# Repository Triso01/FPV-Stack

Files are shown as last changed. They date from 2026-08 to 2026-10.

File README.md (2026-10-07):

# My FPV Stack

Note:
  I made it because I want to learn how to make BLDC-ESCs, 
  Designing my own FPV Stack, it WILL have errors, so do NOT use it in your Drone!
  The 4 in 1 ESC will be continued later, I don not have the experience to finish it yet.
  
## Flight Controller:

- No Analog OSD, made for BetaFPV P1 or optionally Walksnail and DJI
- BEC: 5V 3A; 9V 3A
- IMU (Gyro): ICM-20602
- STM32F405
- Buzzer Pads
- 1 UART free to use e.g. for GPS

ESC and Flight Controller Connector Pinout:

| [1]  | [2] | [3]  | [4]  | [5] | [6] | [7] | [8] |
|---|-----|---|---|-----|-----|-----|-----|
| VBAT | GND | CUR  | TEL  | M1  | M2  | M3  | M4  |



VTX Connector Pinout:

| [1] | [2] | [3]  | [4] | [5] | [6] |
|-----|-----|---|---|-----|-----|
| 5V  | GND | U1_TX| U1_RX | GND | NC  |







## ESCs:
Based on EFM88B21, FD6288 and PSMN1R4-40YLDX.
  - Bluejay (Layout A), BLHeli_S compatible
  - Dshot bidirectional








## ESC distribution board:
10V Buck, 3,3V LDO and the ampmeter









[Will be finished, when I have more experience]:
4in1 ESC:
Based on EFM8BB21, FD6288Q and 24 PSMN1R4-40YLDX.
The PCB size is not final yet, it WILL change.
  - Bluejay (Laout A), BLHeli_S compatible
  - Dshot bidirectional compatible
  - Current Sensor: INA168 with a 0.5mOhms shunt
  - LMR14010 10V Buck to provide Gate voltage
  - AP2204K LDO 10V -> 3.3V
(You can see "pictures" when opening the PCB Files with KiCad)

## What are the boards for?

The Flight Controller (FC) is the main control board and the "brain" of the FPV stack. It runs the flight-control firmware and uses its IMU to measure the drone's movement, which is required for stable flight.

The ESC Distribution Board distributes one battery connection to four individual ESCs. It also generates the 10 V gate-driver supply, and measures the total battery current.

Each Electronic Speed Controller (ESC) drives one three-phase brushless motor. Designing this small, high-current board was the most challenging part of the project.

## Now the expensive things (duhhh):

PCBs:


Settings for FC:



Settings for ESC:



Settings for ESC-Distrib:



(You can change Surface Finish and Color if you want another Color or a higher quality finish)

Parts:
1. Select the columns like this
2. Click "Create BOM"
Bildschirmfoto 2026-09-21 um 22 52 28

3. Click on "Add to Cart"


## Grouped BOM

| Part group | Qty used | Price (USD) |
|---|---:|---:|
| Resistors, including the current shunt | 68 | $3.09 |
| Capacitors | 85 | $9.99 |
| Inductors | 3 | $2.40 |
| Semiconductors and ICs | 57 | $73.05 |
| USB receptacle | 1 | $1.50 |
| Switches | 2 | $0.53 |
| Cables | 6 | $0.00 |
| PCBs | 6 | $103.30 |
| Shipping | 1-2 | ~$20-40 |
| **Total** | | **$195.79** |

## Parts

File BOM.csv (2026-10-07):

Item Name | Qty | Price (total) (USD) | Notes
10 ohm 1% 0201 gate resistor - SAE 1RC0201F1009 | 24 | $0.12 | Replacement for backordered C105901; same value and package. 50 mW is suitable for 24 kHz PWM.
AP2204K-3.3 LDO - AP2204K-3.3TRG1 | 1 | $1.88
121 kohm 1% 0402 resistor - SAE 1RC0402F1213 | 1 | $0.18 | Replacement for backordered C112303; same value and package.
128 Mbit SPI flash - W25Q128JVSIQ | 1 | $2.52
12.4 kohm 1% 0402 resistor - 0402WGF1242TCE | 1 | $0.14
1 kohm 1% 0402 resistor - Yageo RC0402FR-071KL | 2 | $0.38 | Replacement for backordered C11702; same value and package.
22 uH power inductor - Bourns SRP7050TA-220M | 1 | $1.14 | Replacement for backordered C1330991; higher current rating and same footprint, but 4.8 mm high instead of 2.8 mm.
High-side current monitor - INA168NA/3K | 1 | $1.01
10 nF 50 V X7R 0402 capacitor - CL05B103KB5NNNC | 1 | $0.50
0.5 milliohm 2 W 2512 shunt - LR2512-22R0005F4 | 1 | $0.83
Flight-controller MCU - STM32F405RGT6 | 1 | $6.01
1 uF 50 V X5R 0603 capacitor - Taiyo Yuden UMK107BJ105KA-T | 9 | $0.77 | Replacement for backordered C15849; same capacitance, voltage and package.
100 nF 50 V X7R 0603 capacitor - Yageo CC0603KRX7R9BB104 | 4 | $0.62 | Replacement for backordered C1591; same capacitance, voltage and package.
60 V 2 A Schottky diode - SS26 | 1 | $0.60
100 nF 50 V X7R 0805 capacitor - CL21B104KBCNNNC | 4 | $0.30
NPN transistor - BC817-40 | 1 | $0.11
1 uF 50 V X7R 1206 capacitor - AC1206KKX7R9BB105 | 4 | $0.53
40 V 1 A buck converter - LMR14010ADDCT | 1 | $2.39
2.2 uF 16 V X5R 0603 capacitor - CL10A225KO8NNNC | 1 | $0.91
100 kohm 1% 0402 resistor - 0402WGF1003TCE | 2 | $0.25
10 kohm 1% 0402 resistor - 0402WGF1002TCE | 5 | $0.34
200 kohm 1% 0402 resistor - 0402WGF2003TCE | 1 | $0.18
24.9 kohm 1% 0402 resistor - Yageo RC0402FR-0724K9L | 1 | $0.14 | Replacement for backordered C25874; same value and package.
5.1 kohm 1% 0402 resistor - 0402WGF5101TCE | 2 | $0.24
100 kohm 1% 0201 resistor - 0201WMF1003TEE | 12 | $0.15
22 uF 16 V X5R 0603 capacitor - CL10A226MO7JZNC | 4 | $0.34
USB Type-C 16-pin receptacle - TYPE-C 16PIN 2MD(073) | 1 | $1.50
40 V Schottky diode - BAT54KFILM | 12 | $1.43
22 uF 25 V X5R 1206 capacitor - 1206X226M250NT | 1 | $1.22
1 nF 50 V X7R 0201 capacitor - FN03X102K500PLG | 12 | $0.20
100 nF 16 V X5R 0201 capacitor - TCC0201X5R104K160ZT | 20 | $0.22
Three-phase gate driver - Fortior FD6288Q | 4 | $9.49
10 uF 50 V X7R 1210 capacitor - C3225X7R1H106MT000E | 3 | $1.88
40 V LFPAK56 MOSFET - VBsemi VBGED1401 | 24 | $33.12 | Replacement for backordered C458253; same LFPAK56 footprint and 40 V rating, with lower typical RDS(on). Prototype testing is required.
10 kohm 1% 0201 resistor - 0201WMF1002TEE | 16 | $0.14
2.2 uF 10 V X6S 0402 capacitor - GRT155C81A225KE13D | 3 | $0.49
220 nF 50 V X5R 0402 capacitor - GRM155R61H224KE01D | 2 | $0.97
1 uF 25 V X5R 0402 capacitor - CL05A105KA5NQNC | 4 | $0.54
3.0 V LDO - MCP1700T-3002E/TT | 1 | $0.52
2.2 uH power inductor - ANR3015T2R2M | 1 | $0.83
Reset/boot tactile switch - TS-1088-AR02016 | 2 | $0.53
26 V TVS diode - SMBJ26A | 1 | $0.81
3.3 uH power inductor - ANR3015T3R3M | 1 | $0.43
ESC MCU - EFM8BB21F16G-C-QFN20R | 4 | $5.06
40 V 1 A Schottky diode - 1N5819HW-7-F | 1 | $0.57
36 V 3 A buck converter - LMR33630ADDAR | 2 | $1.51
100 nF 50 V X7R 0402 capacitor - CL05B104KB5NNNC | 13 | $0.50
6-axis IMU - ICM-20602 | 1 | $6.02
3-wire ESC connection cable | 4 | $0.00
8-wire FC-to-distribution cable | 1 | $0.00
6-wire VTX cable | 1 | $0.00
ESC distribution PCB | 1 | $49.80
Individual ESC PCB | 4 | $49.50
Flight-controller PCB | 1 | $4.00
JLCPCB estimated shipping | 1 | $21.93
Total Price (USD) |  | $195.79 | Prices checked at LCSC and JLCPCB on 2026-10-07.

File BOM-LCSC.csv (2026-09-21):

Description | Customer Part Number | Package | Quantity | LCSC Part Number
10Ohm | ESC:R2,R3,R4,R5,R6,R7 (x4) | Resistor_SMD:R_0201_0603Metric | 24 | C105901
AP2204K-3.3 | ESC-Verteiler:U1 | Package_TO_SOT_SMD:SOT-23-5 | 1 | C112032
121kOhm | ESC-Verteiler:R8 | Resistor_SMD:R_0402_1005Metric | 1 | C112303
W25Q128JVS | FC:U6 | Package_SO:SOIC-8_5.3x5.3mm_P1.27mm | 1 | C113767
12.4kOhm | FC:R7 | Resistor_SMD:R_0402_1005Metric_Pad0.72x0.64mm_HandSolder | 1 | C11692
1kOhm | FC:R2,R5 | Resistor_SMD:R_0402_1005Metric_Pad0.72x0.64mm_HandSolder | 2 | C11702
22uH | ESC-Verteiler:L1 | Inductor_SMD:L_Bourns_SRP7028A_7.3x6.6mm | 1 | C1330991
INA168 | ESC-Verteiler:U11 | Package_TO_SOT_SMD:SOT-23-5 | 1 | C134294
10nf | FC:C6 | Capacitor_SMD:C_0402_1005Metric_Pad0.74x0.62mm_HandSolder | 1 | C15195
0.5mOhms | ESC-Verteiler:R31 | Resistor_SMD:R_2512_6332Metric | 1 | C154666
STM32F405RGTx | FC:U1 | Package_QFP:LQFP-64_10x10mm_P0.5mm | 1 | C15742
1uf | ESC:C26,C43 (x4); ESC-Verteiler:C1 | Capacitor_SMD:C_0603_1608Metric | 9 | C15849
100nf | ESC:C27 (x4) | Capacitor_SMD:C_0603_1608Metric | 4 | C1591
D | ESC-Verteiler:D1 | Diode_SMD:D_SMA | 1 | C169419
100nf | ESC-Verteiler:C7,C9,C10,C12 | Capacitor_SMD:C_0805_2012Metric | 4 | C1711
BC817 | FC:Q1 | Package_TO_SOT_SMD:SOT-23 | 1 | C181151
1uf | ESC-Verteiler:C6,C8,C11,C13 | Capacitor_SMD:C_1206_3216Metric | 4 | C1853626
LMR14010ADDCT | ESC-Verteiler:U3 | Package_TO_SOT_SMD:TSOT-23-6 | 1 | C2070867
2.2uf | ESC-Verteiler:C2 | Capacitor_SMD:C_0603_1608Metric | 1 | C23630
100kOhm | FC:R3,R6 | Resistor_SMD:R_0402_1005Metric_Pad0.72x0.64mm_HandSolder | 2 | C25741
10kOhm | FC:R1,R8,R9,R10; ESC-Verteiler:R9 | Resistor_SMD:R_0402_1005Metric | 5 | C25744
200kOhm | ESC-Verteiler:R34 | Resistor_SMD:R_0402_1005Metric | 1 | C25764
24.9kOhm | FC:R4 | Resistor_SMD:R_0402_1005Metric_Pad0.72x0.64mm_HandSolder | 1 | C25874
5.1kOhm | FC:R11,R12 | Resistor_SMD:R_0402_1005Metric_Pad0.72x0.64mm_HandSolder | 2 | C25905
100kOhm | ESC:R32,R33,R35 (x4) | Resistor_SMD:R_0201_0603Metric | 12 | C270364
22uf | FC:C17,C18,C21,C22 | Capacitor_SMD:C_0603_1608Metric_Pad1.08x0.95mm_HandSolder | 4 | C2762594
TYPE-C 16PIN 2MD | FC:USB1 | EasyEDA:USB-C-SMD_TYPE-C-16PIN-2MD-073 | 1 | C2765186
BAT54 | ESC:D2,D3,D4 (x4) | Diode_SMD:D_SOD-523 | 12 | C283259
22uf | ESC-Verteiler:C4 | Capacitor_SMD:C_1206_3216Metric | 1 | C2858005
1nf | ESC:C22,C23,C24 (x4) | Capacitor_SMD:C_0201_0603Metric | 12 | C2874741
100nf | ESC:C1,C5,C6,C7,C44 (x4) | Capacitor_SMD:C_0201_0603Metric | 20 | C2903663
FD6288Q | ESC:U2 (x4) | Package_DFN_QFN:HVQFN-24-1EP_4x4mm_P0.5mm_EP2.6x2.6mm | 4 | C328453
10uf | FC:C8,C12; ESC-Verteiler:C5 | Capacitor_SMD:C_1210_3225Metric | 3 | C342670
PSMN1R4-40YLDX | ESC:Q1,Q2,Q3,Q6,Q7,Q8 (x4) | Package_TO_SOT_SMD:LFPAK56 | 24 | C458253
10kOhm | ESC:R1,R36,R37,R38 (x4) | Resistor_SMD:R_0201_0603Metric | 16 | C473048
2.2uF | FC:C5,C27,C28 | Capacitor_SMD:C_0402_1005Metric_Pad0.74x0.62mm_HandSolder | 3 | C5119302
220nf | FC:C7,C11 | Capacitor_SMD:C_0402_1005Metric_Pad0.74x0.62mm_HandSolder | 2 | C5159775
1uf | FC:C1,C2,C9,C13 | Capacitor_SMD:C_0402_1005Metric_Pad0.74x0.62mm_HandSolder | 4 | C52923
MCP1700x-300xxTT | FC:U2 | Package_TO_SOT_SMD:SOT-23 | 1 | C62244
2.2uH | FC:L1 | Inductor_SMD:L_APV_ANR3015 | 1 | C6364793
Taster (RST/BOOT) | FC:SW1,SW2 | EasyEDA:SW-SMD_L3.9-W3.0-P4.45 | 2 | C720477
D | ESC-Verteiler:D14 | Diode_SMD:D_SMB | 1 | C726831
3.3uH | FC:L2 | Inductor_SMD:L_APV_ANR3015 | 1 | C7427087
EFM8BB21F16G-C-QFN20R | ESC:U1 (x4) | Package_DFN_QFN:SiliconLabs_QFN-20-1EP_3x3mm_P0.5mm_EP1.8x1.8mm | 4 | C80713
D | FC:D1 | Diode_SMD:D_SOD-123 | 1 | C82544
LMR33630ADDA | FC:U4,U5 | Package_SO:Texas_HSOP-8-1EP_3.9x4.9mm_P1.27mm_ThermalVias | 2 | C841384
100nf | FC:C3,C4,C10,C14,C15,C16,C19,C20,C23,C24,C25,C26; ESC-Verteiler:C3 | Capacitor_SMD:C_0402_1005Metric | 13 | C960916
ICM-20602 | FC:U3 | Package_LGA:LGA-16_3x3mm_P0.5mm_LayoutBorder3x5y | 1 | C97633

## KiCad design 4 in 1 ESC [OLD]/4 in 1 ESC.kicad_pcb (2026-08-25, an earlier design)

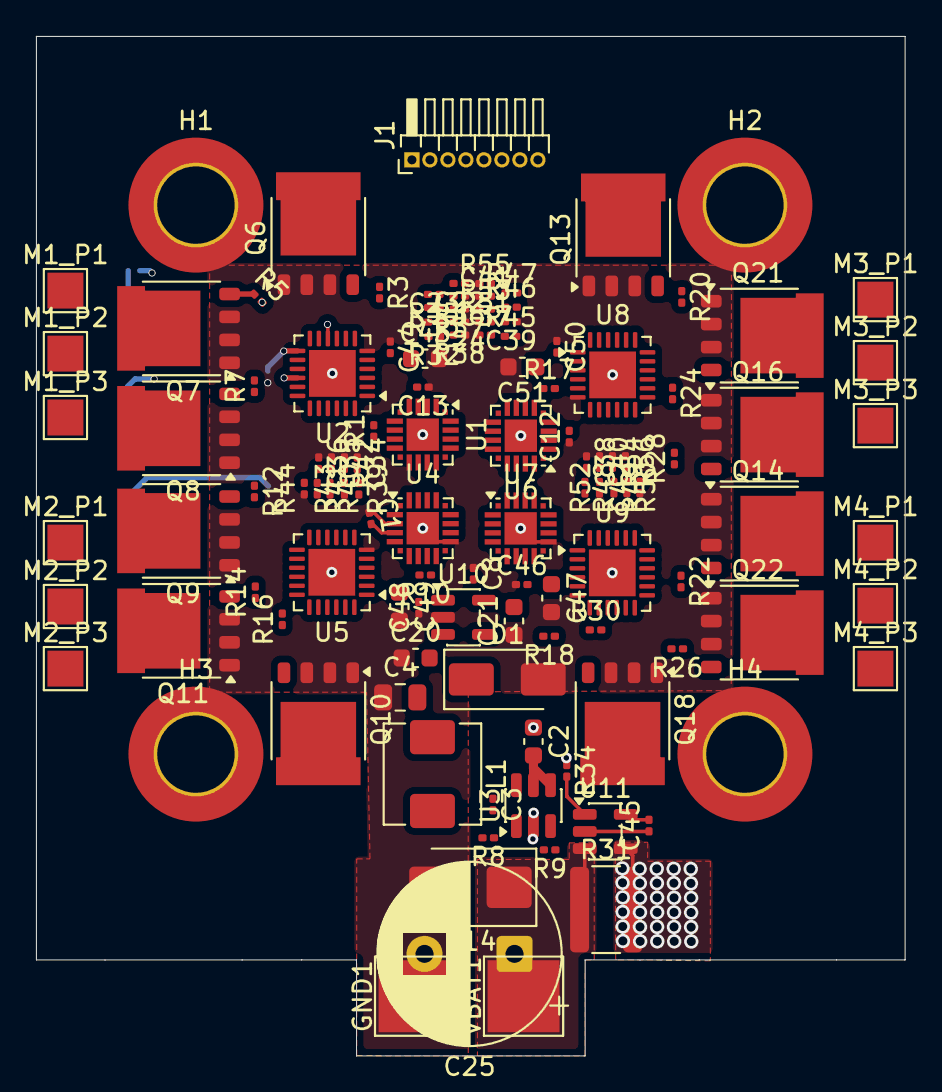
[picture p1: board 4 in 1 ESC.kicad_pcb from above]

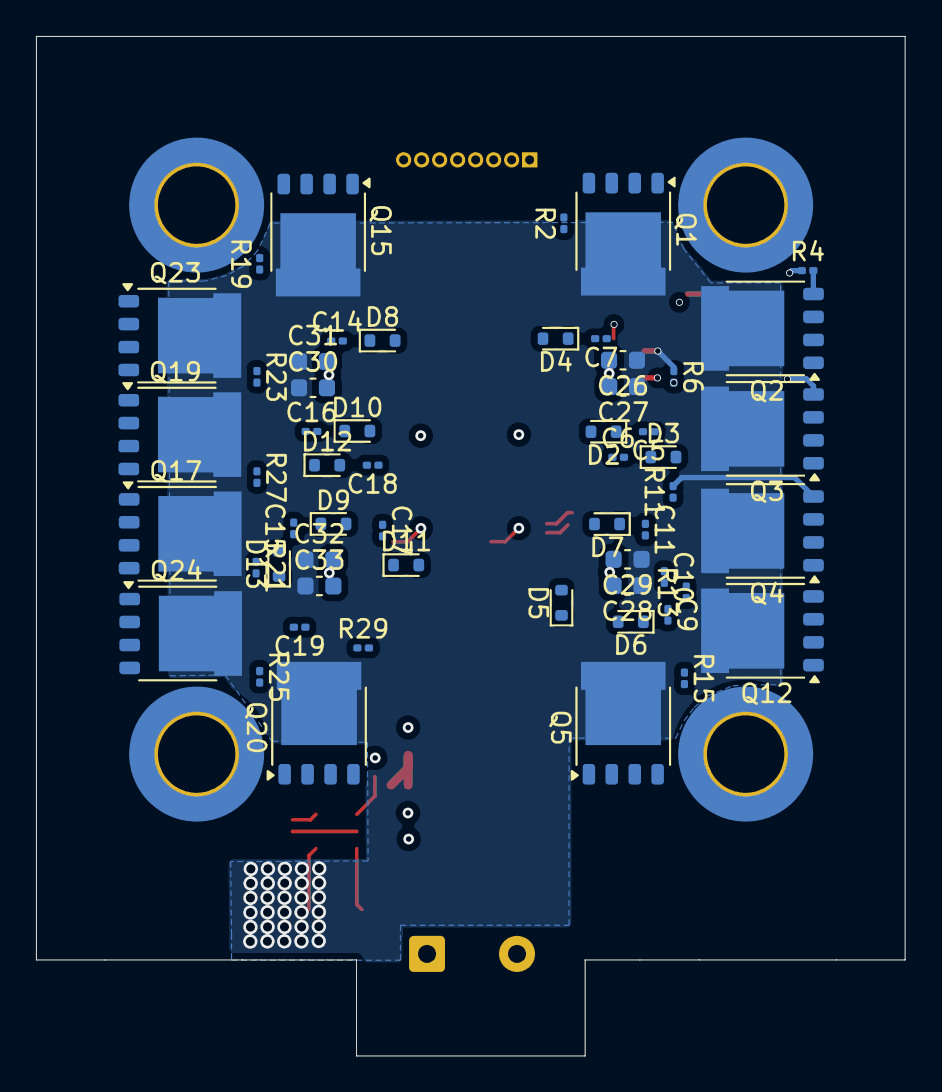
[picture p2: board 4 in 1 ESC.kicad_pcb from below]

Board: 4 copper layers, 48.3 x 56.6 mm, 176 parts (56 on the bottom side), 125 nets.

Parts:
C1, C3, C5, C6, C7, C8, C9, C10, C11, C12, C13, C14, C15, C16, C17, C18, C19, C44, C45, C46, C48, C50: 100nf; C_0201_0603Metric
C2: 10uf; C_0603_1608Metric
C4: 22uf; C_0805_2012Metric
C20, C26, C28, C30, C32, C43, C47, C49, C51: 1uf; C_0603_1608Metric
C21: 2.2uf; C_0603_1608Metric
C22, C23, C24, C34, C35, C36, C37, C38, C39, C40, C41, C42: 1nf; C_0201_0603Metric
C25: 470uf; CP_Radial_D10.0mm_P5.00mm
C27, C29, C31, C33: 100nf; C_0603_1608Metric
D1: D; D_SMA
D2, D3, D4, D5, D6, D7, D8, D9, D10, D11, D12, D13: BAT54; D_SOD-523
D14: D; D_SMB
GND1: TestPoint_Pad_4.0x4.0mm
H1, H2, H3, H4: MountingHole_Pad; MountingHole_4.3mm_M4_DIN965_Pad_TopBottom
J1: Conn_01x08_Socket; PinHeader_1x08_P1.00mm_Horizontal
L1: 22uH; L_Sunlord_MWSA0503S
M1_P1, M1_P2, M1_P3, M2_P1, M2_P2, M2_P3, M3_P1, M3_P2, M3_P3, M4_P1, M4_P2, M4_P3: TestPoint; TestPoint_Pad_2.0x2.0mm
Q1, Q2, Q3, Q4, Q5, Q6, Q7, Q8, Q9, Q10, Q11, Q12, Q13, Q14, Q15, Q16, Q17, Q18, Q19, Q20, Q21, Q22, Q23, Q24: PSMN1R4-40YLDX; LFPAK56
R1, R9, R10, R17, R18, R36, R37, R38, R42, R43, R44, R51, R52, R53, R54, R55, R56: 10kOhm; R_0201_0603Metric
R2, R3, R4, R5, R6, R7, R11, R12, R13, R14, R15, R16, R19, R20, R21, R22, R23, R24, R25, R26, R27, R28, R29, R30: 10Ohm; R_0201_0603Metric
R8: 121kOhm; R_0201_0603Metric
R31: 0.5mOhms; R_1218_3246Metric
R32, R33, R35, R39, R40, R41, R45, R46, R47, R48, R49, R50: 100kOhm; R_0201_0603Metric
R34: 200kOhm; R_0201_0603Metric
U1, U4, U6, U7: EFM8BB21F16G-C-QFN20R; SiliconLabs_QFN-20-1EP_3x3mm_P0.5mm_EP1.8x1.8mm
U2, U5, U8, U9: FD6288Q; HVQFN-24-1EP_4x4mm_P0.5mm_EP2.6x2.6mm
U3: LMR14010ADDCT; TSOT-23-6
U10: AP2204K-3.3; SOT-23-5
U11: INA168; SOT-23-5
VBAT1: TestPoint_Pad_4.0x4.0mm

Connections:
/10V: C4.2, C20.2, C43.1, C44.2, C46.2, C47.1, C48.2, C49.1, C50.2, C51.1, D2.2 (A), D3.2 (A), D4.2 (A), D5.2 (A), D6.2 (A), D7.2 (A), D8.2 (A), D9.2 (A), D10.2 (A), D11.2 (A), D12.2 (A), D13.2 (A), L1.1, R8.2, U2.4 (VCC), U5.4 (VCC), U8.4 (VCC), U9.4 (VCC), U10.1 (VIN), U10.3 (EN)
/CUR: J1.3, R34.2, U11.1
/DSHOT_M1: J1.5, U1.17 (P0.5)
/DSHOT_M2: J1.6, U4.17 (P0.5)
/DSHOT_M3: J1.7, U6.17 (P0.5)
/DSHOT_M4: J1.8, U7.17 (P0.5)
/GND: C1.1, C2.1, C4.1, C8.1, C12.1, C13.1, C20.1, C21.1, C22.1, C23.1, C24.1, C25.2, C26.2, C27.2, C28.2, C29.2, C30.2, C31.2, C32.2, C33.2, C34.1, C35.1, C36.1, C37.1, C38.1, C39.1, C40.1, C41.1, C42.1, C43.2, C44.1, C45.1, C46.1, C47.2, C48.1, C49.2, C50.1, C51.2, D1.2 (A), D14.2 (A), GND1.1 (1_1), H1.1 (1_1), H2.1 (1_1), H3.1 (1_1), H4.1 (1_1), J1.2, Q6.1 (S_1), Q6.2 (S_2), Q6.3 (S_3), Q7.1 (S_1), Q7.2 (S_2), Q7.3 (S_3), Q8.1 (S_1), Q8.2 (S_2), Q8.3 (S_3), Q9.1 (S_1), Q9.2 (S_2), Q9.3 (S_3), Q10.1 (S_1), Q10.2 (S_2), Q10.3 (S_3), Q11.1 (S_1), Q11.2 (S_2), Q11.3 (S_3), Q13.1 (S_1), Q13.2 (S_2), Q13.3 (S_3), Q14.1 (S_1), Q14.2 (S_2), Q14.3 (S_3), Q16.1 (S_1), Q16.2 (S_2), Q16.3 (S_3), Q18.1 (S_1), Q18.2 (S_2), Q18.3 (S_3), Q21.1 (S_1), Q21.2 (S_2), Q21.3 (S_3), Q22.1 (S_1), Q22.2 (S_2), Q22.3 (S_3), R9.2, R34.1, R36.1, R37.1, R38.1, R42.1, R43.1, R44.1, R51.1, R52.1, R53.1, R54.1, R55.1, R56.1, U1.3 (GND), U1.12 (GND), U1.21 (GND), U2.6 (COM), U2.25 (EXP), U3.2 (GND), U4.3 (GND), U4.12 (GND), U4.21 (GND), U5.6 (COM), U5.25 (EXP), U6.3 (GND), U6.12 (GND), U6.21 (GND), U7.3 (GND), U7.12 (GND), U7.21 (GND), U8.6 (COM), U8.25 (EXP), U9.6 (COM), U9.25 (EXP), U10.2 (GND), U11.2 (GND)
/VBAT: C2.2, C26.1, C27.1, C28.1, C29.1, C30.1, C31.1, C32.1, C33.1, J1.1, Q1.5 (D_1), Q2.5 (D_1), Q3.5 (D_1), Q4.5 (D_1), Q5.5 (D_1), Q12.5 (D_1), Q15.5 (D_1), Q17.5 (D_1), Q19.5 (D_1), Q20.5 (D_1), Q23.5 (D_1), Q24.5 (D_1), R31.2, U3.4 (SHDN), U3.5 (VIN), U11.4 (-)
/VDD: C1.2, C8.2, C12.2, C13.2, C21.2, C45.2, R1.1, R10.1, R17.1, R18.1, U1.4 (VDD), U4.4 (VDD), U6.4 (VDD), U7.4 (VDD), U10.5 (VOUT), U11.5 (V+)
/VS1_M1: C5.1, M1_P1.1 (1_1), Q1.1 (S_1), Q1.2 (S_2), Q1.3 (S_3), Q6.5 (D_1), R32.2, U2.18 (VS1)
/VS1_M2: C9.1, M2_P1.1 (1_1), Q4.1 (S_1), Q4.2 (S_2), Q4.3 (S_3), Q9.5 (D_1), R41.2, U5.18 (VS1)
/VS1_M3: C14.1, M3_P1.1 (1_1), Q13.5 (D_1), Q15.1 (S_1), Q15.2 (S_2), Q15.3 (S_3), R47.2, U8.18 (VS1)
/VS1_M4: C15.1, M4_P1.1 (1_1), Q14.5 (D_1), Q17.1 (S_1), Q17.2 (S_2), Q17.3 (S_3), R50.2, U9.18 (VS1)
/VS2_M1: C6.1, M1_P2.1 (1_1), Q2.1 (S_1), Q2.2 (S_2), Q2.3 (S_3), Q7.5 (D_1), R33.2, U2.15 (VS2)
/VS2_M2: C10.1, M2_P2.1 (1_1), Q11.5 (D_1), Q12.1 (S_1), Q12.2 (S_2), Q12.3 (S_3), R40.2, U5.15 (VS2)
/VS2_M3: C16.1, M3_P2.1 (1_1), Q21.5 (D_1), Q23.1 (S_1), Q23.2 (S_2), Q23.3 (S_3), R46.2, U8.15 (VS2)
/VS2_M4: C17.1, M4_P2.1 (1_1), Q22.5 (D_1), Q24.1 (S_1), Q24.2 (S_2), Q24.3 (S_3), R49.2, U9.15 (VS2)
/VS3_M1: C7.1, M1_P3.1 (1_1), Q3.1 (S_1), Q3.2 (S_2), Q3.3 (S_3), Q8.5 (D_1), R35.2, U2.12 (VS3)
/VS3_M2: C11.1, M2_P3.1 (1_1), Q5.1 (S_1), Q5.2 (S_2), Q5.3 (S_3), Q10.5 (D_1), R39.2, U5.12 (VS3)
/VS3_M3: C18.1, M3_P3.1 (1_1), Q16.5 (D_1), Q19.1 (S_1), Q19.2 (S_2), Q19.3 (S_3), R45.2, U8.12 (VS3)
/VS3_M4: C19.1, M4_P3.1 (1_1), Q18.5 (D_1), Q20.1 (S_1), Q20.2 (S_2), Q20.3 (S_3), R48.2, U9.12 (VS3)
unnamed: C3.1, D1.1 (K), L1.2, U3.6 (SW)
unnamed: C5.2, D2.1 (K), U2.20 (VB1)
unnamed: C6.2, D3.1 (K), U2.17 (VB2)
unnamed: C7.2, D4.1 (K), U2.14 (VB3)
unnamed: C9.2, D5.1 (K), U5.20 (VB1)
unnamed: C10.2, D6.1 (K), U5.17 (VB2)
unnamed: C11.2, D7.1 (K), U5.14 (VB3)
unnamed: C14.2, D8.1 (K), U8.20 (VB1)
unnamed: C15.2, D9.1 (K), U9.20 (VB1)
unnamed: C16.2, D10.1 (K), U8.17 (VB2)
unnamed: C17.2, D11.1 (K), U9.17 (VB2)
unnamed: C18.2, D12.1 (K), U8.14 (VB3)
unnamed: C19.2, D13.1 (K), U9.14 (VB3)
unnamed: C25.1, D14.1 (K), R31.1, U11.3 (+), VBAT1.1 (1_1)
unnamed: Q1.4 (G), R2.2
unnamed: Q2.4 (G), R4.2
unnamed: Q3.4 (G), R6.2
unnamed: Q4.4 (G), R11.2
unnamed: Q5.4 (G), R15.2
unnamed: Q6.4 (G), R3.1
unnamed: Q7.4 (G), R5.1
unnamed: Q8.4 (G), R7.1
unnamed: Q9.4 (G), R12.1
unnamed: Q10.4 (G), R16.1
unnamed: Q11.4 (G), R14.1
unnamed: Q12.4 (G), R13.2
unnamed: Q13.4 (G), R20.1
unnamed: Q14.4 (G), R22.1
unnamed: Q15.4 (G), R19.2
unnamed: Q16.4 (G), R28.1
unnamed: Q17.4 (G), R21.2
unnamed: Q18.4 (G), R30.1
unnamed: Q19.4 (G), R27.2
unnamed: Q20.4 (G), R29.2
unnamed: Q21.4 (G), R24.1
unnamed: Q22.4 (G), R26.1
unnamed: Q23.4 (G), R23.2
unnamed: Q24.4 (G), R25.2
unnamed: C24.2, R32.1, R38.2, U1.1 (P0.1)
unnamed: C23.2, R33.1, R37.2, U1.20 (P0.2)
unnamed: C22.2, R35.1, R36.2, U1.19 (P0.3)
unnamed: U1.14 (P1.0), U2.22 (HIN1)
unnamed: U1.13 (P1.1), U2.1 (LIN1)
unnamed: U1.11 (P1.2), U2.23 (HIN2)
unnamed: U1.10 (P1.3), U2.2 (LIN2)
unnamed: U1.9 (P1.4), U2.24 (HIN3)
unnamed: U1.8 (P1.5), U2.3 (LIN3)
unnamed: R1.2, U1.5 (RSTb/C2CK)
unnamed: R2.1, U2.19 (HO1)
unnamed: R4.1, U2.16 (HO2)
unnamed: R6.1, U2.13 (HO3)
unnamed: R3.2, U2.11 (LO1)
unnamed: R5.2, U2.10 (LO2)
unnamed: R7.2, U2.9 (LO3)
unnamed: C3.2, U3.1 (CB)
unnamed: R8.1, R9.1, U3.3 (FB)
unnamed: C36.2, R41.1, R44.2, U4.1 (P0.1)
unnamed: C35.2, R40.1, R43.2, U4.20 (P0.2)
unnamed: C34.2, R39.1, R42.2, U4.19 (P0.3)
unnamed: U4.14 (P1.0), U5.22 (HIN1)
unnamed: U4.13 (P1.1), U5.1 (LIN1)
unnamed: U4.11 (P1.2), U5.23 (HIN2)
unnamed: U4.10 (P1.3), U5.2 (LIN2)
unnamed: U4.9 (P1.4), U5.24 (HIN3)
unnamed: U4.8 (P1.5), U5.3 (LIN3)
unnamed: R10.2, U4.5 (RSTb/C2CK)
unnamed: R11.1, U5.19 (HO1)
unnamed: R13.1, U5.16 (HO2)
unnamed: R15.1, U5.13 (HO3)
unnamed: R12.2, U5.11 (LO1)
unnamed: R14.2, U5.10 (LO2)
unnamed: R16.2, U5.9 (LO3)
unnamed: C41.2, R47.1, R55.2, U6.1 (P0.1)
unnamed: C39.2, R46.1, R53.2, U6.20 (P0.2)
unnamed: C37.2, R45.1, R51.2, U6.19 (P0.3)
unnamed: U6.14 (P1.0), U8.22 (HIN1)
unnamed: U6.13 (P1.1), U8.1 (LIN1)
unnamed: U6.11 (P1.2), U8.23 (HIN2)
unnamed: U6.10 (P1.3), U8.2 (LIN2)
unnamed: U6.9 (P1.4), U8.24 (HIN3)
unnamed: U6.8 (P1.5), U8.3 (LIN3)
unnamed: R17.2, U6.5 (RSTb/C2CK)
unnamed: C42.2, R50.1, R56.2, U7.1 (P0.1)
unnamed: C40.2, R49.1, R54.2, U7.20 (P0.2)
unnamed: C38.2, R48.1, R52.2, U7.19 (P0.3)
unnamed: U7.14 (P1.0), U9.22 (HIN1)
unnamed: U7.13 (P1.1), U9.1 (LIN1)
unnamed: U7.11 (P1.2), U9.23 (HIN2)
unnamed: U7.10 (P1.3), U9.2 (LIN2)
unnamed: U7.9 (P1.4), U9.24 (HIN3)
unnamed: U7.8 (P1.5), U9.3 (LIN3)
unnamed: R18.2, U7.5 (RSTb/C2CK)
unnamed: R19.1, U8.19 (HO1)
unnamed: R23.1, U8.16 (HO2)
unnamed: R27.1, U8.13 (HO3)
unnamed: R20.2, U8.11 (LO1)
unnamed: R24.2, U8.10 (LO2)
unnamed: R28.2, U8.9 (LO3)
unnamed: R21.1, U9.19 (HO1)
unnamed: R25.1, U9.16 (HO2)
unnamed: R29.1, U9.13 (HO3)
unnamed: R22.2, U9.11 (LO1)
unnamed: R26.2, U9.10 (LO2)
unnamed: R30.2, U9.9 (LO3)

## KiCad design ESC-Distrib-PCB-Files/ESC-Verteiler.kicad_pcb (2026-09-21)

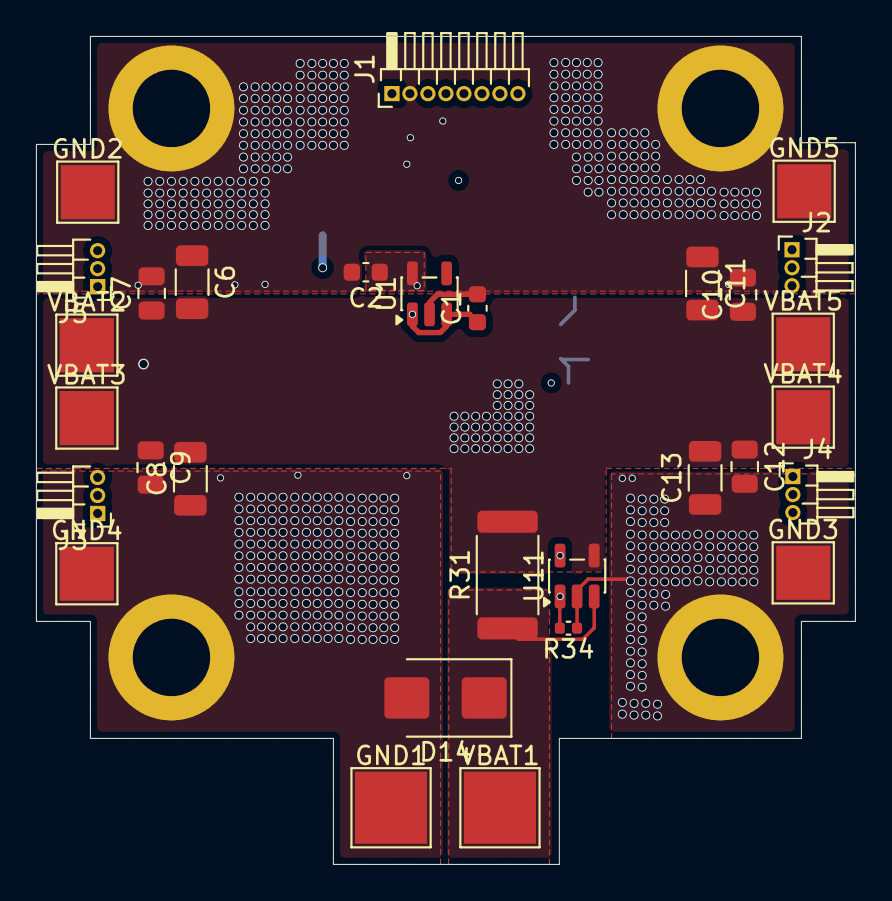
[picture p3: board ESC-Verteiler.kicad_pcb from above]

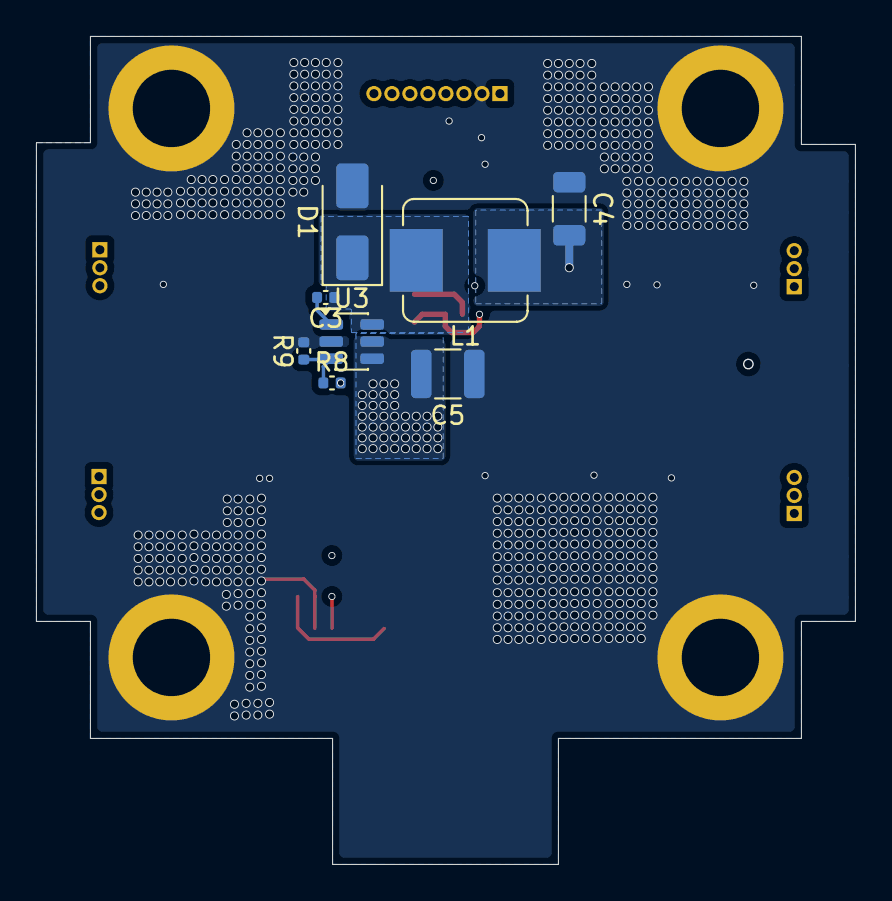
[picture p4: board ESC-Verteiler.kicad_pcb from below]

Board: 4 copper layers, 45.5 x 46.0 mm, 38 parts (8 on the bottom side), 13 nets.

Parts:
C1: 1uf; C_0603_1608Metric
C2: 2.2uf; C_0603_1608Metric
C3: 100nf; C_0402_1005Metric
C4: 22uf; C_1206_3216Metric
C5: 10uf; C_1210_3225Metric
C6, C8, C11, C13: 1uf; C_1206_3216Metric
C7, C9, C10, C12: 100nf; C_0805_2012Metric
D1: D; D_SMA
D14: D; D_SMB
GND1: TestPoint_Pad_4.0x4.0mm
GND2, GND3, GND4, GND5: TestPoint_Pad_3.0x3.0mm
J1: Conn_01x08_Socket; PinHeader_1x08_P1.00mm_Horizontal
J2, J3, J4, J5: Conn_01x03_Pin; PinHeader_1x03_P1.00mm_Horizontal
L1: 22uH; L_Bourns_SRP7028A_7.3x6.6mm
R8: 121kOhm; C_0402_1005Metric
R9: 10kOhm; C_0402_1005Metric
R31: 0.5mOhms; R_2512_6332Metric
R34: 200kOhm; C_0402_1005Metric
U1: AP2204K-3.3; SOT-23-5
U3: LMR14010ADDCT; SOT-23-6
U11: INA168; SOT-23-5
VBAT1: TestPoint_Pad_4.0x4.0mm
VBAT2, VBAT3, VBAT4, VBAT5: TestPoint_Pad_3.0x3.0mm

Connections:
/10V: C1.1, C4.2, J2.1, J3.3, J4.1, J5.3, L1.1, R8.2, U1.1 (VIN), U1.3 (EN)
/CUR: J1.3, R34.2, U11.1
/DSHOT_M1: J1.8, J3.2
/DSHOT_M2: J1.7, J5.2
/DSHOT_M3: J1.6, J2.2
/DSHOT_M4: J1.5, J4.2
/GND: C1.2, C2.2, C4.1, C5.1, C6.1, C7.2, C8.1, C9.2, C10.2, C11.1, C12.2, C13.1, D1.2 (A), D14.2 (A), GND1.1 (1_1), GND2.1 (1_1), GND3.1 (1_1), GND4.1 (1_1), GND5.1 (1_1), J1.2, R9.2, R34.1, U1.2 (GND), U3.2 (GND), U11.2 (GND)
/VBAT: C5.2, C6.2, C7.1, C8.2, C9.1, C10.1, C11.2, C12.1, C13.2, J1.1, R31.2, U3.4 (SHDN), U3.5 (VIN), U11.4 (-), VBAT2.1 (1_1), VBAT3.1 (1_1), VBAT4.1 (1_1), VBAT5.1 (1_1)
/VDD: C2.1, J2.3, J3.1, J4.3, J5.1, U1.5 (VOUT), U11.5 (V+)
unnamed: C3.1, D1.1 (K), L1.2, U3.6 (SW)
unnamed: D14.1 (K), R31.1, U11.3 (+), VBAT1.1 (1_1)
unnamed: C3.2, U3.1 (CB)
unnamed: R8.1, R9.1, U3.3 (FB)

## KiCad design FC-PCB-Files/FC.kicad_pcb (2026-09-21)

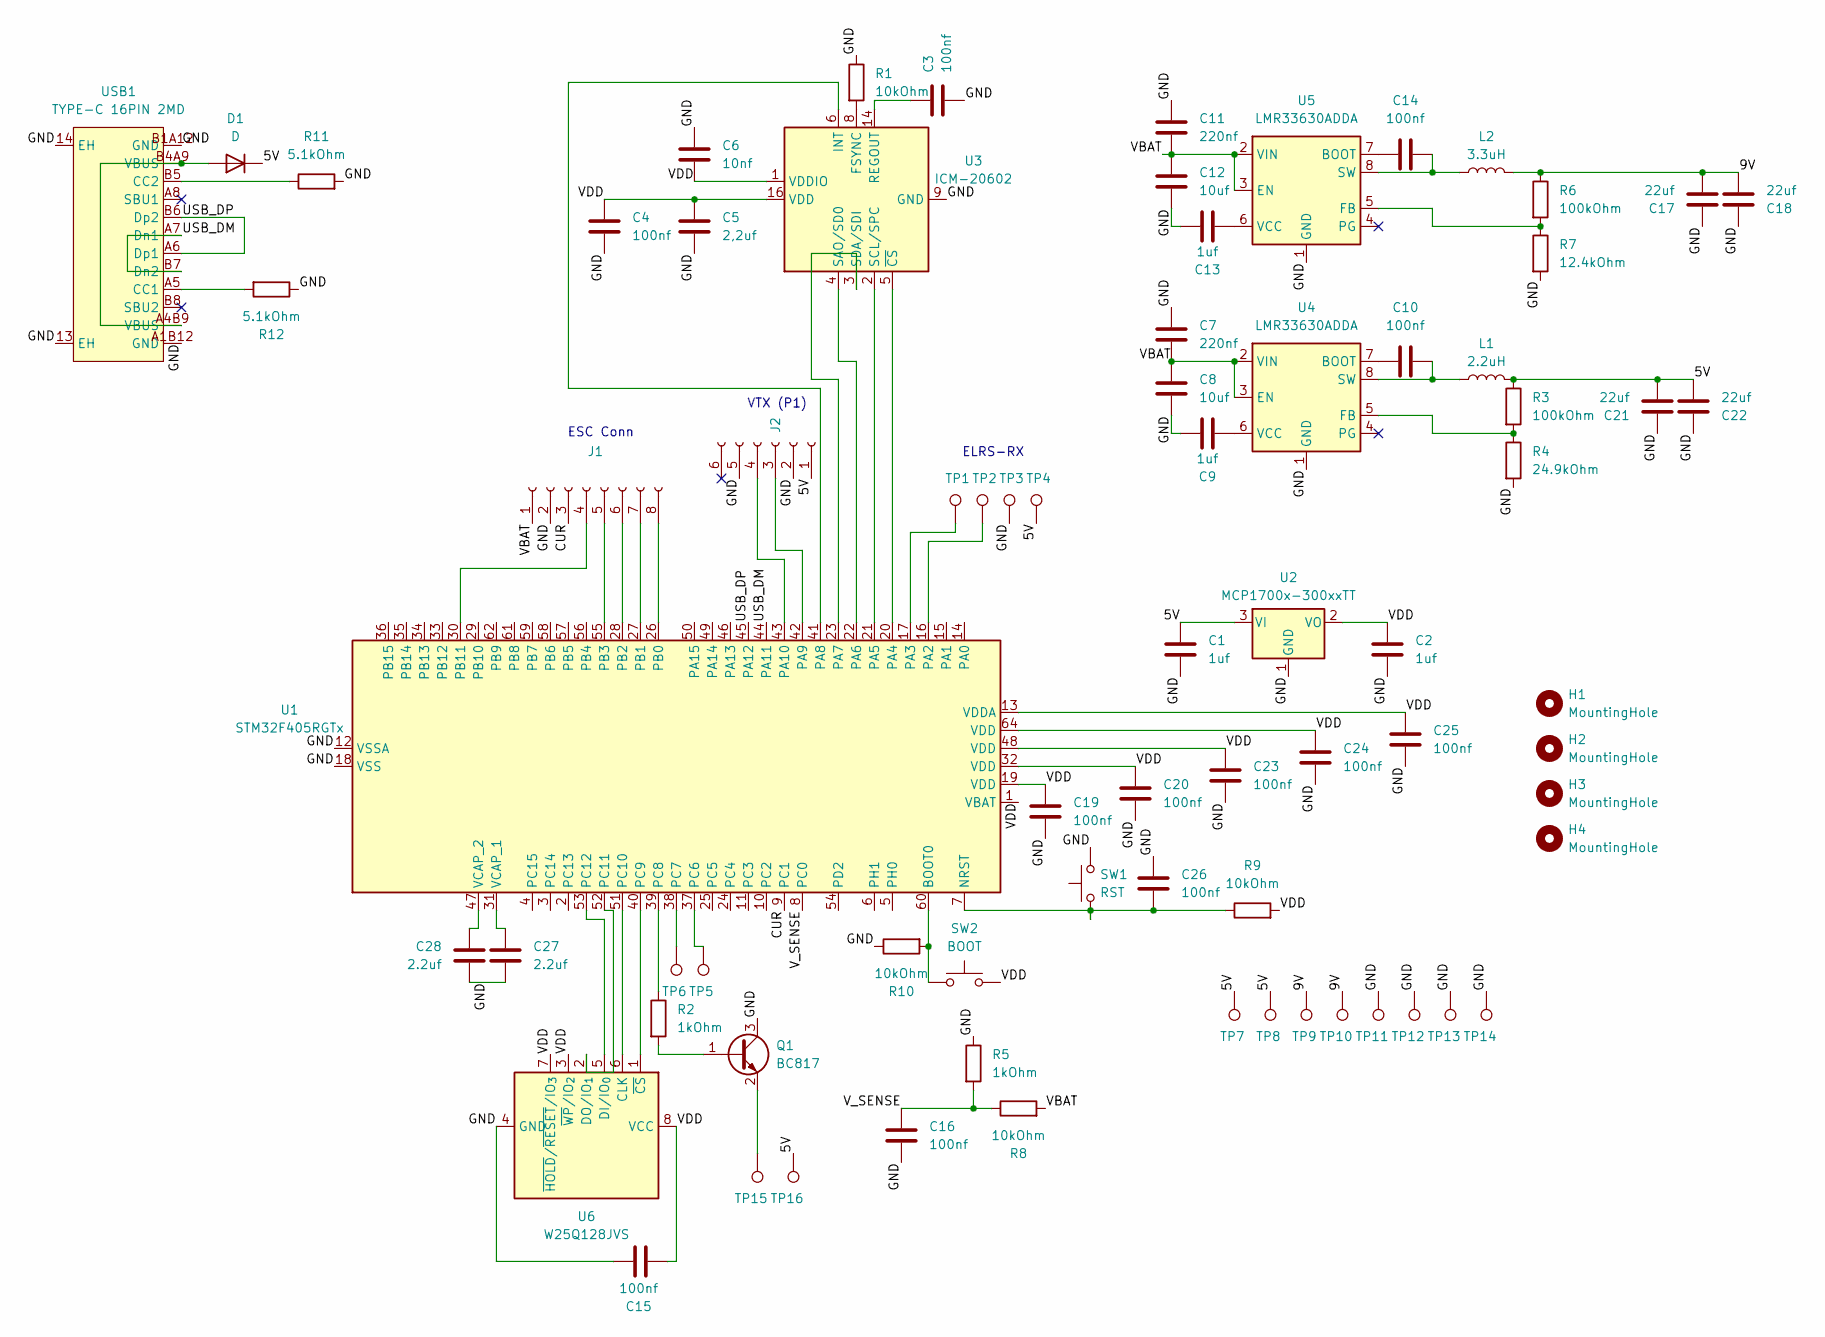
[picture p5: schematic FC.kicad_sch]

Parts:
C1, C2, C9, C13: 1uf; C_0402_1005Metric_Pad0.74x0.62mm_HandSolder
C3, C4, C10, C14, C15, C16, C19, C20, C23, C24, C25, C26: 100nf; C_0402_1005Metric_Pad0.74x0.62mm_HandSolder
C5: 2,2uf; C_0402_1005Metric_Pad0.74x0.62mm_HandSolder
C6: 10nf; C_0402_1005Metric_Pad0.74x0.62mm_HandSolder
C7, C11: 220nf; C_0402_1005Metric_Pad0.74x0.62mm_HandSolder
C8, C12: 10uf; C_0805_2012Metric
C17, C18, C21, C22: 22uf; C_0603_1608Metric_Pad1.08x0.95mm_HandSolder
C27, C28: 2.2uf; C_0402_1005Metric_Pad0.74x0.62mm_HandSolder
D1: D; D_SOD-123
H1, H2, H3, H4: MountingHole; MountingHole_4.3mm_M4_DIN965_Pad_TopOnly
J1: Conn_01x08_Socket; PinHeader_1x08_P1.00mm_Horizontal
J2: Conn_01x06_Socket; PinHeader_1x06_P1.00mm_Horizontal
L1: 2.2uH; L_APV_ANR3015
L2: 3.3uH; L_APV_ANR3015
Q1: BC817; SOT-23
R1, R8, R9, R10: 10kOhm; R_0402_1005Metric_Pad0.72x0.64mm_HandSolder
R2, R5: 1kOhm; R_0402_1005Metric_Pad0.72x0.64mm_HandSolder
R3, R6: 100kOhm; R_0402_1005Metric_Pad0.72x0.64mm_HandSolder
R4: 24.9kOhm; R_0402_1005Metric_Pad0.72x0.64mm_HandSolder
R7: 12.4kOhm; R_0402_1005Metric_Pad0.72x0.64mm_HandSolder
R11, R12: 5.1kOhm; R_0402_1005Metric_Pad0.72x0.64mm_HandSolder
SW1: RST; SW-SMD_L3.9-W3.0-P4.45
SW2: BOOT; SW-SMD_L3.9-W3.0-P4.45
TP1, TP2, TP3, TP4, TP5, TP6, TP7, TP8, TP9, TP10, TP11, TP12, TP13, TP14, TP15, TP16: TestPoint; TestPoint_Pad_D1.5mm
U1: STM32F405RGTx; LQFP-64_10x10mm_P0.5mm
U2: MCP1700x-300xxTT; SOT-23
U3: ICM-20602; LGA-16_3x3mm_P0.5mm_LayoutBorder3x5y
U4, U5: LMR33630ADDA; Texas_HSOP-8-1EP_3.9x4.9mm_P1.27mm_ThermalVias
U6: W25Q128JVS; SOIC-8_5.3x5.3mm_P1.27mm
USB1: TYPE-C 16PIN 2MD; USB-C-SMD_TYPE-C-16PIN-2MD-073; MPN TYPE-C 16PIN 2MD(073); LCSC Part C2765186

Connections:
/5V: C1.1, C21.2, C22.2, D1.1 (K), J2.1, L1.2, R3.1, TP4.1 (1_1), TP7.1 (1_1), TP8.1 (1_1), TP16.1 (1_1), U2.3 (VI)
/9V: C17.2, C18.2, L2.2, R6.1, TP9.1 (1_1), TP10.1 (1_1)
/CUR: J1.3, U1.9 (PC1)
/GND: C1.2, C2.2, C3.2, C4.2, C5.2, C6.1, C7.1, C8.2, C9.2, C11.1, C12.2, C13.2, C15.2, C16.2, C17.1, C18.1, C19.2, C20.2, C21.1, C22.1, C23.2, C24.2, C25.2, C26.1, C27.2, C28.2, J1.2, J2.2, J2.5, Q1.3 (C), R1.1, R4.2, R5.1, R7.2, R10.1, R11.2, R12.1, SW1.2, TP3.1 (1_1), TP11.1 (1_1), TP12.1 (1_1), TP13.1 (1_1), TP14.1 (1_1), U1.12 (VSSA), U1.18 (VSS), U1.63 (VSS), U2.1 (GND), U3.9 (GND), U3.10 (GND), U3.11 (GND), U3.12 (GND), U3.13 (GND), U3.15 (GND), U4.1 (GND), U4.9 (GND), U5.1 (GND), U5.9 (GND), U6.4 (GND), USB1.13 (EH), USB1.14 (EH), USB1.A1B12 (GND), USB1.B1A12 (GND)
/USB_DM: U1.44 (PA11), USB1.A7 (Dn1), USB1.B7 (Dn2)
/USB_DP: U1.45 (PA12), USB1.A6 (Dp1), USB1.B6 (Dp2)
/VBAT: C7.2, C8.1, C11.2, C12.1, J1.1, R8.2, U4.2 (VIN), U4.3 (EN), U5.2 (VIN), U5.3 (EN)
/VDD: C2.1, C4.1, C5.1, C6.2, C15.1, C19.1, C20.1, C23.1, C24.1, C25.1, R9.2, SW2.2, U1.1 (VBAT), U1.13 (VDDA), U1.19 (VDD), U1.32 (VDD), U1.48 (VDD), U1.64 (VDD), U2.2 (VO), U3.1 (VDDIO), U3.16 (VDD), U6.3 (~WP/IO_{2}), U6.7 (~HOLD/~RESET/IO_{3}), U6.8 (VCC)
/V_SENSE: C16.1, R5.2, R8.1, U1.8 (PC0)
unnamed: D1.2 (A), USB1.A4B9 (VBUS), USB1.B4A9 (VBUS)
unnamed: J1.4, U1.30 (PB11)
unnamed: J1.5, U1.55 (PB3)
unnamed: J1.6, U1.28 (PB2)
unnamed: J1.7, U1.27 (PB1)
unnamed: J1.8, U1.26 (PB0)
unnamed: J2.3, U1.42 (PA9)
unnamed: J2.4, U1.43 (PA10)
unnamed: Q1.1 (B), R2.2
unnamed: Q1.2 (E), TP15.1 (1_1)
unnamed: R10.2, SW2.1, U1.60 (BOOT0)
unnamed: C26.2, R9.1, SW1.1, U1.7 (NRST)
unnamed: TP2.1 (1_1), U1.16 (PA2)
unnamed: TP1.1 (1_1), U1.17 (PA3)
unnamed: U1.20 (PA4), U3.5 (~CS)
unnamed: U1.21 (PA5), U3.2 (SCL/SPC)
unnamed: U1.22 (PA6), U3.4 (SAO/SD0)
unnamed: U1.23 (PA7), U3.3 (SDA/SDI)
unnamed: U1.41 (PA8), U3.6 (INT)
unnamed: TP5.1 (1_1), U1.37 (PC6)
unnamed: TP6.1 (1_1), U1.38 (PC7)
unnamed: R2.1, U1.39 (PC8)
unnamed: U1.40 (PC9), U6.1 (~CS)
unnamed: U1.51 (PC10), U6.6 (CLK)
unnamed: U1.52 (PC11), U6.2 (DO/IO_{1})
unnamed: U1.53 (PC12), U6.5 (DI/IO_{0})
unnamed: C27.1, U1.31 (VCAP_1)
unnamed: C28.1, U1.47 (VCAP_2)
unnamed: R1.2, U3.8 (FSYNC)
unnamed: C3.1, U3.14 (REGOUT)
unnamed: C10.1, U4.7 (BOOT)
unnamed: R3.2, R4.1, U4.5 (FB)
unnamed: C10.2, L1.1, U4.8 (SW)
unnamed: C9.1, U4.6 (VCC)
unnamed: C14.1, U5.7 (BOOT)
unnamed: R6.2, R7.1, U5.5 (FB)
unnamed: C14.2, L2.1, U5.8 (SW)
unnamed: C13.1, U5.6 (VCC)
unnamed: R12.2, USB1.A5 (CC1)
unnamed: R11.1, USB1.B5 (CC2)

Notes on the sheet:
VTX (P1)
ELRS-RX
ESC Conn

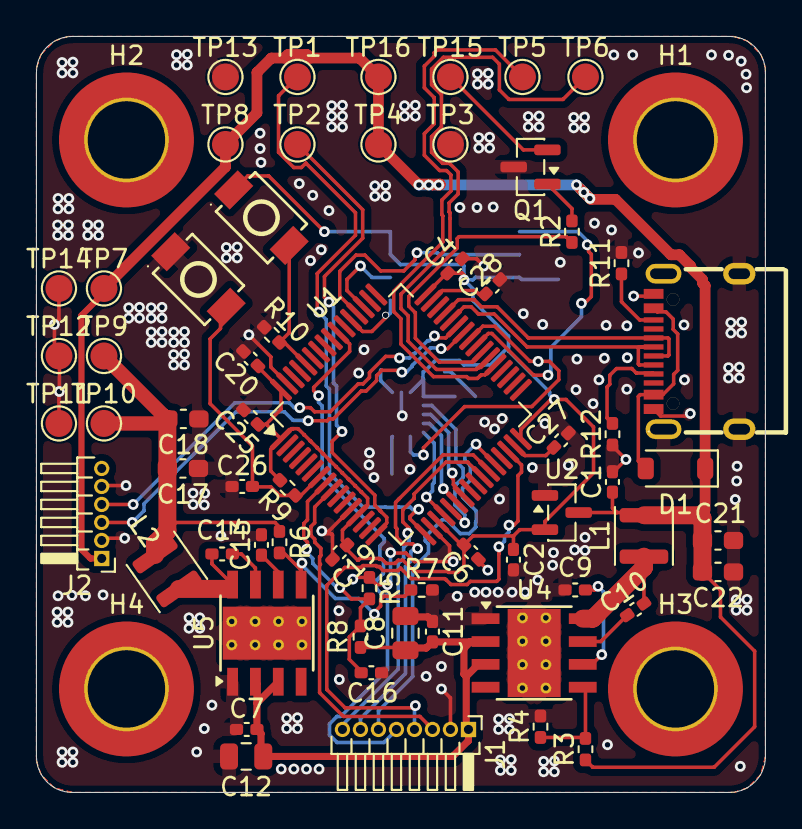
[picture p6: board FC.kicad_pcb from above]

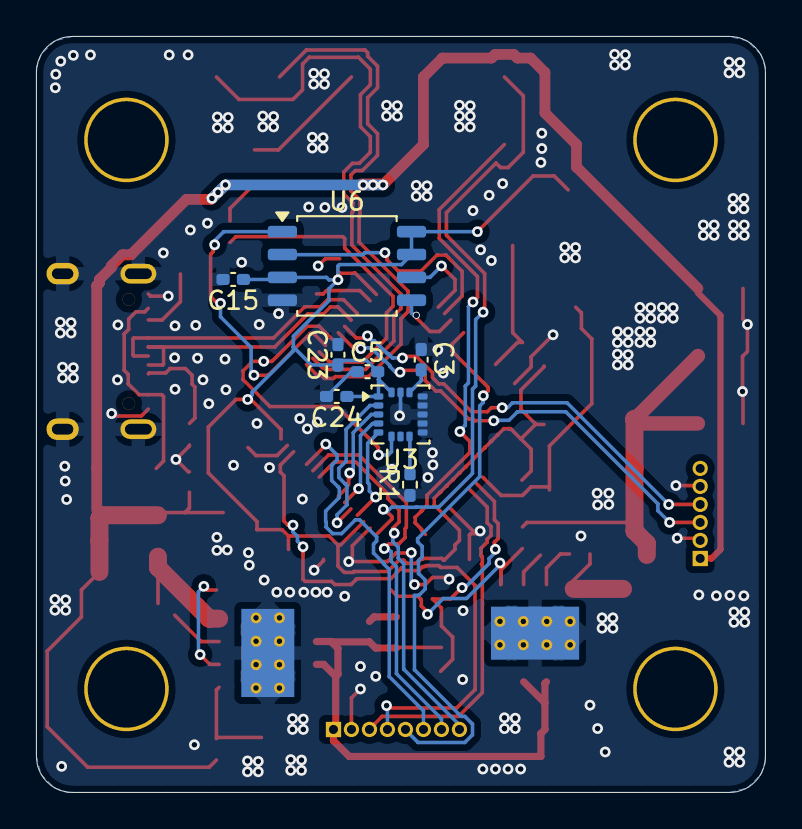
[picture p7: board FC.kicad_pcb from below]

Board: 2 copper layers, 40.5 x 42.0 mm, 75 parts (8 on the bottom side), 49 nets.

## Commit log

2026-08-17 Update README with flight controller
    Added detailed specifications for the flight controller and 4in1 ESC.
2026-08-28 Update README with FPV stack and ESC information
    Added notes about the FPV stack and ESC details, including layout and compatibility.
2026-09-18 Update README with new images and ESC details
    Added multiple images and ESC distribution board details to README.
2026-09-21 Create 4 in 1 ESC [Old]
2026-09-21 Add BOM for FPV Stack with ESC x4
    [FPV-Stack_LCSC_BOM_for_every_part (ESC x4).csv]
2026-09-21 Same as FPV-Stack_LCSC_BOM_for_every_part (ESC x4).csv
2026-09-21 Update README with expensive items section
    Added new section detailing expensive items including PCBs and parts selection process.
2026-09-21 Clean up BOM CSV formatting
    Removed unnecessary characters and cleaned up BOM CSV format.
    [FPV-Stack_LCSC_BOM_for_every_part (ESC x4).csv]
2026-09-21 Clean up BOM CSV by removing duplicates
    Removed duplicate header and adjusted BOM entries.
    [FC_LCSC-JLCPCB_BOM.csv]
2026-09-21 Fix BOM formatting in ESC_LCSC-JLCPCB_BOM.csv
    Removed BOM entries and re-added them with correct formatting.
    [ESC_LCSC-JLCPCB_BOM.csv]
2026-09-21 Fix BOM formatting and remove duplicate header
    Removed extra BOM header and adjusted formatting.
    [ESC-Verteiler_LCSC-JLCPCB_BOM.csv]
2026-09-22 Update README with settings images for FC and ESC
    Added settings images for FC, ESC, and ESC-Distrib.
2026-09-22 Update README with settings images
    Added images for FC, ESC, and ESC-Distrib settings.
2026-10-07 Enhance README with board functionality descriptions
    Added explanations for the Flight Controller, ESC Distribution Board, and ESC.
2026-10-07 Improve clarity of board descriptions in README
    Revised descriptions of Flight Controller, ESC Distribution Board, and ESC for clarity and detail.
2026-10-07 Update ESC Distribution Board description in README
    Removed mention of the 3.3 V supply for ESC logic in the description of the ESC Distribution Board.
2026-10-07 Add BOM.csv with component details and pricing
    Added a Bill of Materials (BOM) CSV file containing item details, quantities, prices, and notes for components used in the project.
    [BOM.csv]
